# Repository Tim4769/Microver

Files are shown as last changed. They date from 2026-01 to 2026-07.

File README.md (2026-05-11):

# Microver

Microver rover

Microver is a compact rover built for the Swiss Rover Challenge. This repository collects the project's electronics, mechanical CAD, software scaffold, PCB test firmware, photos, and shared assets in one place.

## Project

- **Competition:** Swiss Rover Challenge, Switzerland's rover competition for teams of 5 high school students.
- **2025 result:** 3rd place.
- **2026 result:** 1st place.
- **Main disciplines:** electronics, mechanical design, and software.

## Start Here

| Area | Path | Contents |
|---|---|---|
| Electronics | `hardware/final/README.md` | Active PCB revisions, KiCad projects, manufacturing outputs, and validation notes. |
| Mechanical | `mechanical/README.md` | Rover assemblies, wheel pods, chassis parts, mechanisms, mounts, and STEP exports. |
| Software | `software/` | Python rover-control scaffold with camera and control services. |
| PCB test firmware | `hardware/pcb_testing_firmware/README.md` | Arduino sketches and docs for board bring-up and electronics validation. |
| Power diagrams | `hardware/flow_charts/README.md` | Power-system flow charts and supporting diagrams. |

## Current Snapshot

**Electronics**
- Manufacturing-ready PCB work is under `hardware/final/`; archived board spins live under `hardware/archive/`.
- The active stack covers protection Rev B, boost Rev C, buck Rev C, high-side OR-ing Rev A, compute Rev A, and final control Rev A.

**Mechanical**
- Modular CAD lives in `mechanical/assemblies/` and `mechanical/components/`.
- The rover uses field-serviceable wheel pods, aluminium extrusion rails, custom 3D-printed parts, and integrated mounts for electronics, sensors, and mechanisms.

**Software**
- `software/` is the autonomy-ready rover software workspace for control, camera, perception, navigation, and system integration.
- `hardware/pcb_testing_firmware/` contains electronics bring-up and validation sketches only; it is separate from the final software stack.

## Repository Map

- `hardware/` - PCB designs, manufacturing files, archived board revisions, power diagrams, and PCB validation firmware.
- `mechanical/` - CAD assemblies, exported STEP components, manufacturing notes, and mechanical integration references.
- `software/` - Raspberry Pi control software scaffold and future rover software workspace.
- `photos/` - Build, test, and competition photos.
- `logo/` - Current and legacy logo assets.
- `jingle/` - Project audio assets.
- `Microver_presentation_final.pdf` - Final presentation and system overview.

## Maintenance Notes

- Keep generated PCB outputs inside the relevant board revision folder.
- Update CAD references when board dimensions, connector orientation, sensor placement, or mounting details change.
- Keep editable CAD, exported review files, and assembly notes together.
- Keep PCB validation sketches separate from final rover software.
- Update this README when top-level folders move or new subsystem entry points are added.

## License / Contact

All rights reserved. No permission is granted to use, copy, modify, or distribute this repository or its contents without prior written consent. See `LICENSE` for exact terms.

Contact: Tim Wang - timwang007@outlook.com.

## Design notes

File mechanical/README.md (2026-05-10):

# Hardware — Mechanical

## Overview

Microver is a compact competition rover built for the [Swiss Rover Challenge](../Documentation/Swiss-Rover-Challenge-Rulebook-2026-v1.pdf). The mechanical design prioritises modularity — the wheel pod system supports both 4-wheel and 6-wheel drive configurations by sliding in and out of aluminium extrusion rails, making field reconfiguration straightforward. All structural parts are custom 3D printed, with the complete assembly designed in Autodesk Fusion 360.

---

## Folder Structure

```
hardware/
├── assemblies/                  # Full and sub-assembly STEP files
│   ├── Microver assembly.step   # Top-level full rover assembly
│   └── Wheel pod assembly.step  # Modular wheel pod sub-assembly
└── components/
    ├── Chassis/                 # Base plate and aluminium extrusions
    ├── body/                    # Hood, mechanisms, servo mounts, and body parts
    ├── drivetrain/              # Wheel pod internal components
    └── electronics/             # PCBs, mounts, and power components
```

---

## Assemblies

### Full Rover — `assemblies/Microver assembly.step`

Top-level assembly of the complete rover, combining all sub-assemblies and components.

---

### Wheel Pod Assembly — `assemblies/Wheel pod assembly.step`

A modular drivetrain unit that slides in and out of the aluminium extrusion rails, enabling 4WD or 6WD configurations without structural modification. One assembly is used per wheel.

| File | Type | Description |
|---|---|---|
| `drivetrain/hub.step` | Custom | Wheel hub |
| `drivetrain/Motor Coupler.step` | Custom | Couples DC motor shaft to wheel hub |
| `drivetrain/motor holder.step` | Custom | Holds DC motor within the pod |
| `drivetrain/wheel covers with hole in the middle.step` | Custom | Wheel cap/cover |
| `drivetrain/dc-motor-encoder.step` | Manufacturer | DC motor with integrated encoder |
| `drivetrain/Ball bearing.step` | Off-the-shelf | Standard ball bearing |
| `body/extrusion connector component.step` | Custom | Interfaces wheel pod to aluminium extrusion rail |

---

### Chassis

The structural frame of the rover. The base plate mounts onto aluminium extrusion rails via L-brackets, which also act as the sliding rails for the wheel pod assemblies.

| File | Type | Description |
|---|---|---|
| `Chassis/base plate final.step` | Custom | Main structural plate — 30×15.8 cm (overall width 34×19.5 cm) |
| `Chassis/aluminium extrusion.step` | Off-the-shelf | Aluminium extrusion rails |
| `body/L-bracket.step` | Off-the-shelf | HBLBS5 L-bracket, connects extrusions to base plate |

---

### Hook Mechanism

A large MG996R servo drives a hook arm used to grab small payloads and deliver them to a stash location.

| File | Type | Description |
|---|---|---|
| `body/hook microver.step` | Custom | Hook arm |
| `body/servo motor v4 continuation.step` | Custom | Custom MG996R servo mount/bracket |
| `body/Servo+MG996R.step` | Manufacturer | MG996R servo |

---

### Trap Box Assembly

A servo-operated mechanism that releases small pellets from beneath the rover. The pellets are dropped behind the rover to cause competing rovers to slip.

| File | Type | Description |
|---|---|---|
| `body/Trap box.step` | Custom | Pellet container housing |
| `body/MG90S_motorholder.step` | Custom | MG90S servo mount |
| `body/MG90S servo.step` | Manufacturer | MG90S servo (trap door actuation) |

---

### Flag Mechanism

A small MG90S servo raises a flag on the side of the rover.

| File | Type | Description |
|---|---|---|
| `body/Flag holder.step` | Custom | Flag arm/holder |
| `body/MG90S_motorholder.step` | Custom | MG90S servo mount |
| `body/MG90S servo.step` | Manufacturer | MG90S servo (flag actuation) |

---

### Hood Assembly

A 3-part protective cover for the rover's internal components. Also serves as the mounting platform for the camera, LIDAR, and WiFi antenna.

| File | Type | Description |
|---|---|---|
| `body/Microver hood.step` | Custom | Hood (front, main, and back sections) |
| `body/LIDAR.step` | Manufacturer | Slamtec C1M1 LIDAR — used for autonomous navigation |
| `body/RPi_Camera_V2.1.step` | Manufacturer | Raspberry Pi Camera V2.1 |

---

## Component Catalogue

### Custom Designed Parts

| Component | File | Description |
|---|---|---|
| Base plate | `Chassis/base plate final.step` | Main structural plate, 30×15.8 cm |
| Aluminium extrusion connector | `body/extrusion connector component.step` | Wheel pod–to–extrusion rail interface |
| Wheel hub | `drivetrain/hub.step` | Wheel hub |
| Motor coupler | `drivetrain/Motor Coupler.step` | Shaft-to-hub coupling |
| Motor holder | `drivetrain/motor holder.step` | DC motor mount within wheel pod |
| Wheel cover | `drivetrain/wheel covers with hole in the middle.step` | Wheel cap |
| Hood | `body/Microver hood.step` | 3-part protective body cover |
| Hook arm | `body/hook microver.step` | Payload hook arm |
| MG996R servo mount | `body/servo motor v4 continuation.step` | Large servo bracket |
| MG90S servo holder | `body/MG90S_motorholder.step` | Small servo mount (shared by trap & flag) |
| Trap box | `body/Trap box.step` | Pellet dispenser housing |
| Flag holder | `body/Flag holder.step` | Flag arm |
| Fan mount | `body/Fan microver.step` | Electronics cooling fan mount |
| Fan holder | `body/fan holder.step` | Secondary fan bracket |
| PCB mount | `electronics/PCB mount.step` | PCB mounting bracket |
| Raspberry Pi 5 holder | `electronics/Pi5_holder.step` | Raspberry Pi 5 mount |
| PCB spacer | `electronics/Spacer PCB.step` | PCB standoff spacer |
| Logo model | `body/CK Project model.step` | Project CK logo |

### Manufacturer / Off-the-Shelf Models

| Component | File | Source |
|---|---|---|
| Aluminium extrusion | `Chassis/aluminium extrusion.step` | microver.ch competition |
| L-bracket (HBLBS5) | `body/L-bracket.step` | microver.ch competition |
| MG996R servo | `body/Servo+MG996R.step` | microver.ch competition |
| MG90S servo | `body/MG90S servo.step` | microver.ch competition |
| DC motor w/ encoder | `drivetrain/dc-motor-encoder.step` | microver.ch competition |
| Ball bearing | `drivetrain/Ball bearing.step` | microver.ch competition |
| LIDAR (Slamtec C1M1) | `body/LIDAR.step` | microver.ch competition |
| Raspberry Pi Camera V2.1 | `body/RPi_Camera_V2.1.step` | microver.ch competition |
| Raspberry Pi 5 | `electronics/Raspberry Pi.step` | Electronics supplier |
| Einhell 2.5Ah battery | `electronics/Battery/einhell-2.5Ah.step` | microver.ch competition |
| Power receiver | `electronics/Battery/power-receiver-public-document.step` | microver.ch competition |
| E-stop | `electronics/e-stop.step` | microver.ch competition |
| Boost converter PCB | `electronics/Boost converter_3D.step` | Custom PCB manufacturer |
| Buck converter PCB | `electronics/Buck_3D.step` | Custom PCB manufacturer |
| High Side OR-ing PCB | `electronics/High Side OR ing_3D.step` | Custom PCB manufacturer |
| Modular board PCB | `electronics/Microver2026_Modular_Final_3D.step` | Custom PCB manufacturer |
| STM32 control PCB | `electronics/Microver2026_STM32_Control_3D.step` | Custom PCB manufacturer |

---

## Manufacturing

All custom parts were designed in Autodesk Fusion 360 and 3D printed in-house.

**Printers:** Bambu Lab H2D and X1C

**Materials:**
- **PLA Basic** — all structural parts
- **TPU** — tyres (for maximum grip and elasticity)

**Sourcing:** Off-the-shelf hardware components (brackets, extrusions, motors, sensors) were sourced from the microver.ch competition. Electronics were sourced separately.

---

## Status

All parts are finalised as of the 2026 competition season.

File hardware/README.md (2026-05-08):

# Hardware Index

Use this index to avoid opening stale revisions by accident.

## Start here
- `final/README.md` - Latest board revisions (active work only).

## Historical revisions
- `archive/README.md` - Archived revisions and legacy boards.

## Important after folder moves
- KiCad output paths in project files may still point to old folder locations.
- After moving a board revision, update KiCad plot and export paths (Gerber, drill, BOM, CPL) before regenerating manufacturing outputs.

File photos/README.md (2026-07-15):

# Photos

Project photos for Microver design, build, testing, and competition documentation.

## Folders
- `2024-2025/` - Earlier design, testbench, and development photos.
- `2025-2026/` - Final rover, build, electronics, and competition-season photos.

Keep board-specific engineering photos inside the relevant board folder when they document a PCB revision. Use this folder for project-level photos.

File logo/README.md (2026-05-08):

# Logo Assets

Logo source files, exports, and legacy reference images for Microver branding.

## Folders
- `logos_current/` - Current logo source and export files.
- `logos_legacy/` - Older logo files kept for reference only.

Use the current folder for new presentations, documentation, and public-facing materials unless a legacy file is explicitly needed for comparison.

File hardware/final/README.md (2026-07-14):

# Current Hardware (Start Here)

These are the active board folders. Use these for new builds and current engineering updates.
Each board folder keeps its working KiCad project in a local `Kicad_*` subdirectory next to generated manufacturing files when those outputs are available.

## Complete Board Assembly

Complete Microver hardware stack with every board assembled together

*This photo shows every board assembled together as the complete hardware stack, not only the final control board.*

- `protection_board_manufacturing_rev_b/`
- `boost_manufacturing_rev_c/`
- `buck_manufacturing_rev_c/`
- `High_Side_OR_ing_manufacturing_rev_a/`
- `final_compute_STM32_rev_a/`
- `final_compute_arduinos_rev_a/`
- `final_control_board_rev_a/`

Field testing and competition notes for the motor-driver voltage mismatch, boost/buck removal, motor change, Raspberry Pi power-drop hypotheses, and second motor-driver `OUTA` / `OUTB` rework are recorded in `final_control_board_rev_a/README.md`.

Archived or superseded board folders live under `../archive/`.

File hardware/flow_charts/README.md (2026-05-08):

# Flow Charts

Exported power-system flow-chart images for Microver hardware handoff and review.

## Files
- `Power system.png` - Full power-system overview.
- `Power system - Protection.png` - Protection-board path.
- `Power system - Buck.png` - Buck-converter path.
- `Power system - Boost.png` - Boost-converter path.
- `Power system - ORing.png` - High-side OR-ing path.

Keep exported diagrams here as PNGs. If an editable source file is added later, keep it in this folder and refresh the PNG exports with the same names when possible.

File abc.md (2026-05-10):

<<<<<<< HEAD
# Microver

Microver rover

Microver is a small rover project organized around three equally important parts: electronics, mechanical design, and software. The project was built for the Swiss Rover Challenge, Switzerland's high-school robotics championship where teams design, build, and operate Mars rover prototypes.

This repository keeps the project work together: final board files, mechanical handoff material, future rover software space, PCB testing firmware, documentation, and shared project assets.

## Project 
**Swiss Rover Challenge**
- Format: teams of 3-4 high-school students build and operate Mars rover prototypes.
- 2025 edition: Institut Le Rosey, Rolle, Switzerland, Saturday, May 31, 2025.
- 2026 edition: College Alpin Beau Soleil, Villars-sur-Ollon, Switzerland, Sunday, May 3, 2026.

**Team roles**
- Tim / Tianran Wang - team lead and electrical engineer.
- Lucas / Haolin Liu - software engineer.
- Taiyo - software engineer.
- Pat / Chawanvit Tangwongsiri - mechanical engineer.
- Steven Bang - mechanical engineer.

**Team results**
- 2025 Swiss Rover Challenge: 3rd place.
- 2026 Swiss Rover Challenge: 1st place.

## Project Parts
**Electronics**
- Purpose: power entry, conversion, motor drive, compute interconnects, and final rover control boards.
- Start here: `hardware/final/README.md`.
- Supporting material: `flow_charts/README.md` for power-system diagrams.
- Completed status: active board work lives under `hardware/final/`; older spins remain under `hardware/archive/`.

**Mechanical**
- Purpose: CAD, mounting, chassis, packaging, and physical integration for the rover.
- Start here: `mechanical/README.md`.
- Supporting material: board photos and physical reference files inside the hardware folders.
- Completed status: mechanical handoff area is tracked and ready for final CAD, drawings, assembly notes, and mount details.

**Software**
- Purpose: Raspberry Pi control software, Arduino motor/encoder firmware, diagnostics, pin maps, messaging, and handoff documentation.
- Start here: `firmware/README.md`.
- Supporting material: `pcb_testing_firmware/README.md` for electronics bring-up and PCB validation sketches.
- Current status: `firmware/` is reserved for the rover software lead to update later; existing Arduino test code lives in `pcb_testing_firmware/` and is not the competition software.

## Current Snapshot
**Electronics**
- Protection board: Rev B.
- Boost converter: Rev C.
- Buck converter: Rev C.
- High-side OR-ing board: Rev A.
- Final compute boards: STM32 Rev A and dual-Arduino Rev A.
- Final control board: Rev A.

**Mechanical**
- Mechanical folder is tracked and documented.
- `mechanical/placeholder.rtf` is present until final CAD or drawing files are added.
- Future mechanical files should keep source CAD, exported drawings, assembly notes, and mounting references together.
- Mechanical integration should stay aligned with board footprints, connector access, and software sensor/actuator assumptions.

**Software**
- `firmware/` is a placeholder for the future rover software maintained by the software lead.
- `pcb_testing_firmware/` contains PCB testing, electronics bring-up sketches, diagnostics, and references.
- `pcb_testing_firmware/archive/2024_code/` contains older experiments for historical reference.
- Existing test sketches should be treated as board validation tools, not as the final competition software stack.
- The final presentation describes the competition software architecture as a Raspberry Pi Python host communicating with two Arduino Nano Every boards over serial: one for motors/servos and one for encoder data.
- The planned control stack included joystick remote control, live camera feed, low-level PID, Pure Pursuit, and AMCL localization using LIDAR.

## Repository Map
**Electronics**
- `hardware/` - Board projects and release organization.
- `hardware/final/` - Latest board revisions for the completed 2026 rover.
- `hardware/archive/` - Historical board revisions and rollback references.
- `flow_charts/` - Exported power-system flow-chart PNGs.

**Mechanical**
- `mechanical/` - Mechanical handoff area for CAD, drawings, mounts, and assembly notes.

**Software**
- `firmware/` - Future rover software folder for the software lead.
- `pcb_testing_firmware/` - PCB testing and electronics bring-up firmware.
- `pcb_testing_firmware/2026/` - Final-stack board validation sketches and handoff notes.
- `pcb_testing_firmware/2025/` - Earlier Arduino testing sketches, diagnostics, docs, and references.
- `pcb_testing_firmware/archive/` - Legacy experiments and older code snapshots.

**Shared Assets**
- `Microver_presentation_final.pdf` - Final presentation with team roles, project timeline, and system overview.
- `logo/` - Current and legacy logo assets.
- `jingle/` - Microver jingle audio files.
- `photos/` - Project photos from design, build, testing, and competition seasons.
- `LICENSE` - All rights reserved terms.

## Quick Start
**Electronics**
- Start in `hardware/final/` and choose the latest revision folder for the board you are building, reviewing, or documenting.
- Use each board's local `Kicad_*` folder for schematic/layout changes.
- Use `Gerber/`, `Gerber.zip`, `BOM.csv`, and `CPL.csv` when generated manufacturing outputs are available.
- For protection-board validation, use `hardware/final/protection_board_manufacturing_rev_b/test_procedure_rev_b.md`.

**Mechanical**
- Start in `mechanical/` and replace the placeholder with source CAD, exported drawings, or assembly notes when available.
- Keep mechanical files organized by rover subsystem or assembly if the folder grows.
- Check board dimensions, mounting holes, connector access, and cable paths against the active electronics folders.
- Add assembly notes next to the related CAD/drawing files so the physical build is traceable.

**Software**
- Start in `firmware/` when adding the future rover software.
- Use `pcb_testing_firmware/2026/docs/board-validation-software-handoff.md` only for board validation pin maps and test flow.
- Use `pcb_testing_firmware/2026/docs/power-and-actuator-control-handoff.md` for power-control and actuator bring-up notes.
- Run focused test sketches from `pcb_testing_firmware/2026/controllers/` when validating PCBs or electronics.

## Detailed Navigation
**Electronics**
- `hardware/final/protection_board_manufacturing_rev_b/` - Latest protection board.
- `hardware/final/boost_manufacturing_rev_c/` - Latest boost converter.
- `hardware/final/buck_manufacturing_rev_c/` - Latest buck converter.
- `hardware/final/High_Side_OR_ing_manufacturing_rev_a/` - Latest high-side OR-ing board.
- `hardware/final/final_compute_STM32_rev_a/` - STM32 compute board.
- `hardware/final/final_compute_arduinos_rev_a/` - Dual-Arduino compute board.
- `hardware/final/final_control_board_rev_a/` - Main control and distribution board.

**Mechanical**
- `mechanical/README.md` - Mechanical folder guide.
- `mechanical/placeholder.rtf` - Temporary tracked placeholder.
- Board photos in `hardware/final/*/Photo.JPG` are useful physical references for mechanical integration.

**Software**
- `firmware/README.md` - Future rover software folder guide.
- `pcb_testing_firmware/2026/controllers/` - Final-stack PCB testing sketches.
- `pcb_testing_firmware/2026/docs/board-validation-software-handoff.md` - Board validation pin maps, serial commands, and test flow.
- `pcb_testing_firmware/2026/docs/power-and-actuator-control-handoff.md` - Power and actuator bring-up notes.
- `pcb_testing_firmware/2025/diagnostics/` - Earlier focused subsystem checks.

## Maintenance Notes
**Electronics**
- After KiCad edits, regenerate Gerbers, drill files, BOM, CPL, and assembly drawings as needed.
- Keep generated outputs inside the relevant board folder.
- Add test logs as `test_procedure_<rev>.md` or `validation_notes.md`.

**Mechanical**
- Keep editable source files and exported review files together.
- Record fit, clearance, mounting, and assembly changes in README or notes files near the CAD.
- When electronics move or connector orientation changes, update mechanical references at the same time.

**Software**
- Keep future rover software under `firmware/`.
- Keep PCB validation sketches under `pcb_testing_firmware/`.
- Keep pin-map changes synchronized with the hardware and mechanical layout.
- Document PCB test protocol, baud-rate, actuator, and watchdog changes in `pcb_testing_firmware/2026/docs/`.

## License / Contact
All rights reserved. No permission is granted to use, copy, modify, or distribute this repository or its contents without prior written consent. See `LICENSE` for exact terms. Contact: Tim Wang - timwang007@outlook.com.
=======
# microver

```bash
make
```
>>>>>>> 239cfc1 (Pushing code)

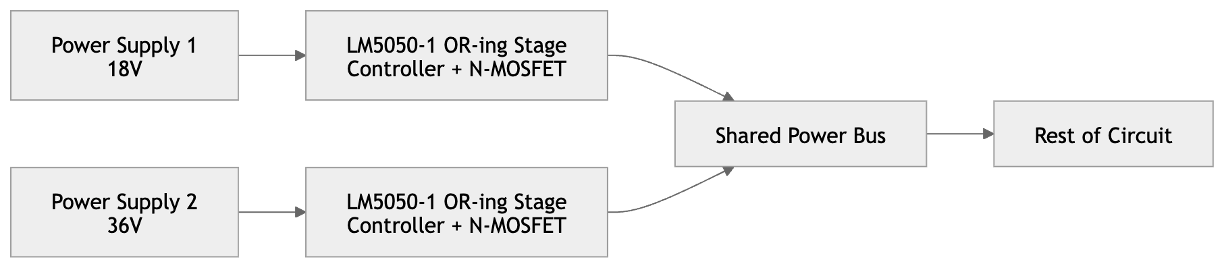
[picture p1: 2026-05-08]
hardware/flow_charts/Power system - ORing.png

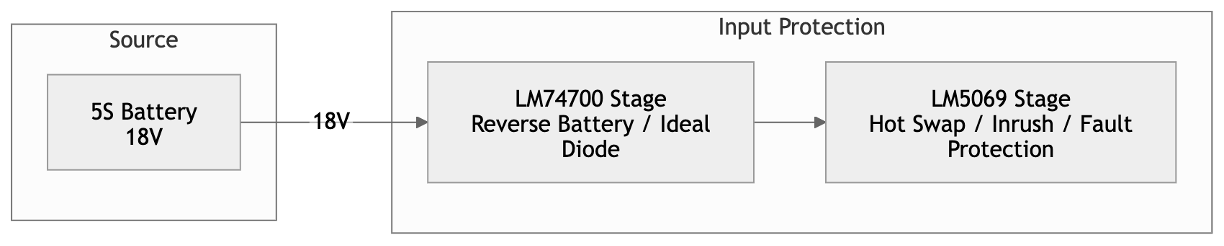
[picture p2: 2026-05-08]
hardware/flow_charts/Power system - Protection.png

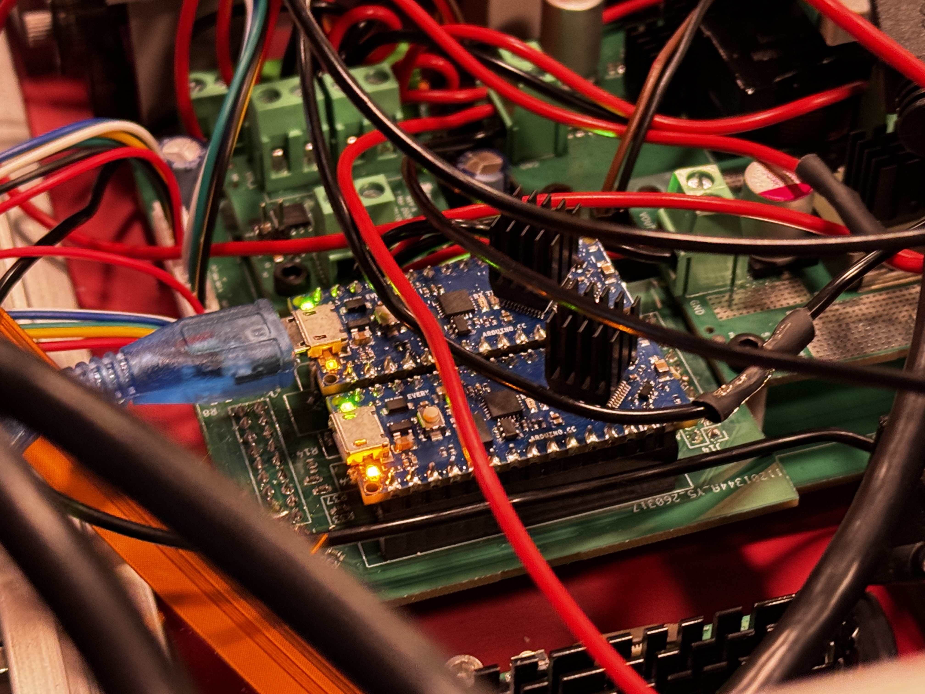
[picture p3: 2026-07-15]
hardware/final/final_compute_arduinos_rev_a/Photo.JPG

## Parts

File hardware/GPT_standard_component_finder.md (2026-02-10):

# Standard Component Finder GPT

## What it does
- Finds the closest standard resistor or capacitor values to a user-specified target, covering the entire range (including ultra-low and ultra-high values).
- Uses only commonly stocked E-series values (E12 or E24) and basic-library parts.
- Always returns three buckets per query: best match, nearest lower, nearest higher.
- Proposes up to three-part combinations (series/parallel) when they yield a closer effective value.
- Reports percentage error for every result, including perfect matches (0%).
- Responds concisely and technically—no extra context (voltage, tolerance, dielectric, etc.).

## Output style
- Clean table or bullet list with columns/fields for: configuration (single / series / parallel), component values used, computed equivalent, and % error.
- Applies the same format to single values and multi-component combos.
- No prompting required for range extremes; it auto-considers all valid E12/E24 values.

## Creation notes (prompt highlights)
- Primary goal: “Identify standard resistor/capacitor options that best match a target value using E12/E24 values; include nearest lower/higher and small combinations up to three parts; show % error for every entry.”
- Constraints: basic-library parts only; keep answers short and technical; exclude contextual advice.
- Combination logic: compute series/parallel equivalents, pick the closest match, and still surface the next lower/higher single-value options.
- Formatting rule: always include a % error column/field, even when the error is 0%.

## Usage
1) Provide a target value (e.g., “82 kΩ” or “3.3 µF”). No extra parameters needed.
2) The GPT responds with best/nearest-lower/nearest-higher single values plus any tighter series/parallel combos (up to 3 parts), each with % error.
3) Copy the suggested standard values directly into schematics/BOMs as needed.

## Link
- ChatGPT GPT: https://chatgpt.com/g/g-696bbc706f4c8191a6ac34a9fc48d9c7-standard-value-finder

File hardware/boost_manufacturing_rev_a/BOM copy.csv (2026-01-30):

Reference | Qty | Value | Footprint | Datasheet | JPCPCB part number
C1,C4,C7 | 3 | 220uF | Capacitor_THT:CP_Radial_D10.0mm_P5.00mm | ~ | C106670
C2,C5,C8,C10 | 4 | 100nF | Capacitor_SMD:C_0603_1608Metric | ~ | C14663
C3 | 1 | 1uF | Capacitor_SMD:C_0805_2012Metric | ~ | C28323
C6 | 1 | 6.8uF | Capacitor_SMD:C_0603_1608Metric | ~ | C338096
C9 | 1 | 47nF | Capacitor_SMD:C_0603_1608Metric | ~ | C1622
D1,D2 | 2 | D_TVS | Diode_SMD:D_SMB | ~ | C19077586
D3 | 1 | D_Schottky | Diode_SMD:D_SMC | ~ | C134457
D4 | 1 | 1N4148W | Diode_SMD:D_SOD-123 | https://www.vishay.com/docs/85748/1n4148w.pdf | C7420318
J1,J3 | 2 | Conn_01x02_Socket | TerminalBlock:TerminalBlock_MaiXu_MX126-5.0-02P_1x02_P5.00mm | ~
J2 | 1 | Conn_01x02_Socket | Connector_PinHeader_2.54mm:PinHeader_1x02_P2.54mm_Vertical | ~
Q1,Q2,Q3 | 3 | CSD19536KTT | KTT0002A | https://www.ti.com/lit/gpn/csd19536ktt | C2687963
R1,R5 | 2 | 47kΩ | Resistor_SMD:R_0603_1608Metric | ~ | C25819
R2,R6 | 2 | 620Ω | Resistor_SMD:R_0603_1608Metric | ~ | C23220
R3 | 1 | 180Ω | Resistor_SMD:R_0603_1608Metric | ~ | C22828
R4 | 1 | 7.5kΩ | Resistor_SMD:R_0603_1608Metric | ~ | C23234
R7 | 1 | 4.3kΩ | Resistor_SMD:R_0603_1608Metric | ~ | C23159
R8 | 1 | 33Ω | Resistor_SMD:R_0603_1608Metric | ~ | C23140
R9,R10 | 2 | 5mΩ | Resistor_SMD:R_2512_6332Metric | ~ | C108931
R11,R12 | 2 | 10Ω | Resistor_SMD:R_0603_1608Metric | ~ | C22859
R13 | 1 | 22kΩ | Resistor_SMD:R_0603_1608Metric | ~ | C31850
R14 | 1 | 100kΩ | Resistor_SMD:R_0603_1608Metric | ~ | C25803
R15 | 1 | 1kΩ | Resistor_SMD:R_0603_1608Metric | ~ | C21190
U1 | 1 | LM74700QDBVRQ1 | DBV0006A_N | https://www.ti.com/lit/gpn/lm74700-q1 | C2941042
U2 | 1 | LM5069MMX-2/NOPB | MUB10A | https://www.ti.com/lit/gpn/lm5069 | C2653582
U3 | 1 | MMBT5401LT1G | SOT-23-3_1P4X3P040_ONS | MMBT5401LT1G | C21488

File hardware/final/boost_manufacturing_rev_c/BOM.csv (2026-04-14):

Reference | Qty | Value | Footprint | Datasheet | JLCPCB Part number
C1 | 1 | 150pF | Capacitor_SMD:C_0603_1608Metric | ~ | C1594
C2 | 1 | 470nF | Capacitor_SMD:C_0805_2012Metric | ~ | C13967
C3 | 1 | 220nF | Capacitor_SMD:C_0603_1608Metric | ~ | C21120
C4 | 1 | 1uF | Capacitor_SMD:C_0805_2012Metric | ~ | C28323
C5 | 1 | 470nF | Capacitor_SMD:C_0603_1608Metric | ~ | C1623
C6 | 1 | 680pF | Capacitor_SMD:C_0603_1608Metric | ~ | C1630
C7 | 1 | 220nF | Capacitor_SMD:C_0805_2012Metric | ~ | C5378
C8,C9,C11,C13,C14,C15,C16,C17,C18,C19,C20 | 11 | 10uF | Capacitor_SMD:C_0805_2012Metric | ~ | C440198
C10,C12 | 2 | 470uF | Capacitor_THT:CP_Radial_D10.0mm_P5.00mm | ~ | C5438877
D1 | 1 | D_Schottky | Diode_SMD:D_SMA | ~ | C18199198
J1,J2 | 2 | Conn_01x02_Socket | TerminalBlock_MetzConnect:TerminalBlock_MetzConnect_Type055_RT01502HDWU_1x02_P5.00mm_Horizontal | ~
J4 | 1 | Conn_01x02_Pin | Connector_PinHeader_2.54mm:PinHeader_1x02_P2.54mm_Vertical | ~
L1 | 1 | 10uH | Boost_Converter_Footprint_Library:IND_SER2918H_COC | ~ | C3037600
MOSFET1 | 1 | 2N7002 | Boost_Converter_Footprint_Library:SOT-23TO-236_318-08_ONS | 2N7002 | C8545
Q1,Q2,Q3,Q4 | 4 | CSD18540Q5B | Boost_Converter_Footprint_Library:DNK0008A | https://www.ti.com/lit/gpn/csd18540q5b | C86513
R1 | 1 | 49.9kΩ | Resistor_SMD:R_0603_1608Metric | ~ | C23184
R2 | 1 | 5.1kΩ | Resistor_SMD:R_0603_1608Metric | ~ | C23186
R3,R13 | 2 | 100Ω | Resistor_SMD:R_0603_1608Metric | ~ | C22775
R4 | 1 | 3.01Ω | Resistor_SMD:R_0603_1608Metric | ~ | C49655781
R5 | 1 | 2mΩ | Resistor_SMD:R_2512_6332Metric | ~ | C728306
R6,R8 | 2 | 160kΩ | Resistor_SMD:R_0603_1608Metric | ~ | C22813
R7,R12 | 2 | 56kΩ | Resistor_SMD:R_0603_1608Metric | ~ | C23206
R9,R16,R17,R18 | 4 | 2Ω | Resistor_SMD:R_0603_1608Metric | ~ | C22977
R10 | 1 | 2kΩ | Resistor_SMD:R_0603_1608Metric | ~ | C22975
R11 | 1 | 12kΩ | Resistor_SMD:R_0603_1608Metric | ~ | C22790
R14 | 1 | 1.5kΩ | Resistor_SMD:R_0603_1608Metric | ~ | C22843
R15 | 1 | 270kΩ | Resistor_SMD:R_0603_1608Metric | ~ | C22965
U1 | 1 | LM5122QMHX/NOPB | Boost_Converter_Footprint_Library:HTSSOP20 | https://www.ti.com/lit/gpn/lm5122-q1 | C527477

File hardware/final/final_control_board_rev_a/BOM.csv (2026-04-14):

Reference | Qty | Value | Exclude from BOM | Footprint | JLCPCB Part Number
C1,C3,C7,C16 | 4 | 220uF |  | Capacitor_THT:CP_Radial_D8.0mm_P3.50mm | C106697
C2,C6 | 2 | 4.7uF |  | Capacitor_SMD:C_0603_1608Metric | C19666
C4,C5 | 2 | 4.7 uF |  | Capacitor_SMD:C_1206_3216Metric | C29823
C8,C9 | 2 | 220 uF |  | Capacitor_SMD:CP_Elec_4x5.4 | C116389
D1 | 1 | 3.3V |  | LED_SMD:LED_0603_1608Metric | C126319
D2 | 1 | 5V |  | LED_SMD:LED_0603_1608Metric | C22371297
D3 | 1 | 18V |  | LED_SMD:LED_0603_1608Metric | C22371297
F1 | 1 | Fuse |  | microver footprint Library:Fuse PTF-77 | C717030
H2 | 1 | Boost/Prot | Excluded from BOM | MountingHole:MountingHole_3.2mm_M3
H3 | 1 | Prot | Excluded from BOM | MountingHole:MountingHole_3.2mm_M3
H4,H5,H6,H8,H9,H10,H11,H12,H13,H14 | 10 | MountingHole | Excluded from BOM | MountingHole:MountingHole_3.2mm_M3
J1 | 1 | Fan control |  | Connector_PinHeader_2.54mm:PinHeader_1x03_P2.54mm_Vertical | C2937625
J2 | 1 | PGD_Prot |  | Connector_PinHeader_2.54mm:PinHeader_1x02_P2.54mm_Vertical | C492401
J3 | 1 | on/off_Boost |  | Connector_PinHeader_2.54mm:PinHeader_1x02_P2.54mm_Vertical | C492401
J10 | 1 | Drive_1 |  | Connector_JST:JST_PH_B6B-PH-K_1x06_P2.00mm_Vertical
J11 | 1 | Drive_2 |  | Connector_JST:JST_PH_B6B-PH-K_1x06_P2.00mm_Vertical
J12 | 1 | Drive_3 |  | Connector_JST:JST_PH_B6B-PH-K_1x06_P2.00mm_Vertical
J13 | 1 | Drive_4 |  | Connector_JST:JST_PH_B6B-PH-K_1x06_P2.00mm_Vertical
J14 | 1 | Left |  | Connector_PinHeader_2.54mm:PinHeader_2x10_P2.54mm_Vertical | C492427
J15 | 1 | Right |  | Connector_PinHeader_2.54mm:PinHeader_2x10_P2.54mm_Vertical | C492427
J16 | 1 | Drive_5 |  | Connector_JST:JST_PH_B6B-PH-K_1x06_P2.00mm_Vertical
J17 | 1 | Drive_6 |  | Connector_JST:JST_PH_B6B-PH-K_1x06_P2.00mm_Vertical
J18 | 1 | Lidar pins |  | Connector_JST:JST_XH_B5B-XH-AM_1x05_P2.50mm_Vertical
J19 | 1 | VIN_5V |  | Connector_Wire:SolderWire-0.75sqmm_1x02_P7mm_D1.25mm_OD3.5mm | C8269
J20 | 1 | Spare pins |  | Connector_PinHeader_2.54mm:PinHeader_1x05_P2.54mm_Vertical | C492404
J24 | 1 | Servo 1 |  | Connector_PinHeader_2.54mm:PinHeader_1x03_P2.54mm_Vertical | C2937625
J25 | 1 | Servo 2 |  | Connector_PinHeader_2.54mm:PinHeader_1x03_P2.54mm_Vertical | C2937625
J26 | 1 | Servo 3 |  | Connector_PinHeader_2.54mm:PinHeader_1x03_P2.54mm_Vertical | C2937625
J27 | 1 | Servo 4 |  | Connector_PinHeader_2.54mm:PinHeader_1x03_P2.54mm_Vertical | C2937625
J28 | 1 | VOUT_Higher |  | Connector_Wire:SolderWire-0.75sqmm_1x02_P7mm_D1.25mm_OD3.5mm | C8269
J29 | 1 | Pi 5 TX and RX UART0 (PL011) |  | Connector_PinHeader_2.54mm:PinHeader_1x02_P2.54mm_Vertical | C492401
J30 | 1 | Pi power pins |  | Connector_PinHeader_2.54mm:PinHeader_1x02_P2.54mm_Vertical | C492401
J31 | 1 | VIN_Pre |  | TerminalBlock:TerminalBlock_MaiXu_MX126-5.0-02P_1x02_P5.00mm | C8269
J32 | 1 | VOUT_Pre |  | Connector_Wire:SolderWire-0.75sqmm_1x02_P7mm_D1.25mm_OD3.5mm | C8269
R1 | 1 | 330Ω |  | Resistor_SMD:R_0603_1608Metric | C23138
R2 | 1 | 1.2kΩ |  | Resistor_SMD:R_0603_1608Metric | C22765
R3 | 1 | 6.8kΩ |  | Resistor_SMD:R_0603_1608Metric | C23212
SW1 | 1 | 1MS1T1B1M2QES |  | Microver2026_Modular_Footprint:SS-12D10G5_XKB | C319012
SW2 | 1 | SW_SPDT |  | Connector_Wire:SolderWire-0.5sqmm_1x03_P4.8mm_D0.9mm_OD2.3mm
TH1 | 1 | Thermistor_NTC | Excluded from BOM | microver footprint Library:NTC thermistor Microver
TP1 | 1 | +5V | Excluded from BOM | TestPoint:TestPoint_Pad_1.0x1.0mm
TP2 | 1 | +3.3V | Excluded from BOM | TestPoint:TestPoint_Pad_1.0x1.0mm
TP3,TP4 | 2 | Compute/ENCO_PWR | Excluded from BOM | TestPoint:TestPoint_Pad_1.0x1.0mm
U1,U2 | 2 | VNH5019A-E |  | Buck_Footprint_Library:SOIC_5019A-E_STM | C2653552
U3,U4 | 2 | CSD18543Q3A |  | Buck_Footprint_Library:DNH0008A | C840100
U5 | 1 | MIC5365-3.3YD5 |  | Package_TO_SOT_SMD:SOT-23-5 | C626098

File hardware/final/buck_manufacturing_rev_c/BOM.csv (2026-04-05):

Reference | Qty | Value | Footprint | Datasheet | JLCPCB Part Number
C1 | 1 | 220 uF | Capacitor_SMD:CP_Elec_4x5.4 | ~ | C116389
C2,C3,C4,C6,C7,C9 | 6 | 4.7 uF | Capacitor_SMD:C_1206_3216Metric | ~ | C29823
C5 | 1 | 2.2 μF | Capacitor_SMD:C_0805_2012Metric | ~ | C377773
C8 | 1 | 1uF | Capacitor_SMD:C_0603_1608Metric | ~ | C15849
C10,C12 | 2 | 0.1 μF | Capacitor_SMD:C_0603_1608Metric | ~ | C14663
C11 | 1 | 10 pF | Capacitor_SMD:C_0603_1608Metric | ~ | C1634
C13 | 1 | 4.7nF | Capacitor_SMD:C_0603_1608Metric | ~ | C53987
C14 | 1 | 68pF | Capacitor_SMD:C_0603_1608Metric | ~ | C28262
C15,C16,C18,C19,C20,C22,C23 | 7 | 47 μF | Capacitor_SMD:C_1210_3225Metric | ~ | C96123
C17 | 1 | 2.7nF | Capacitor_SMD:C_0603_1608Metric | ~ | C1609
C21 | 1 | 680 µF | Buck_Footprint_Library:MA35V680M10X13 | ~ | C48971043
C24 | 1 | 1nF | Capacitor_SMD:C_0603_1608Metric | ~ | C1588
D1 | 1 | R LED | LED_SMD:LED_0603_1608Metric | ~ | C2286
J1,J2 | 2 | Conn_01x02_Socket | TerminalBlock:TerminalBlock_MaiXu_MX126-5.0-02P_1x02_P5.00mm | ~ | C8269
L1 | 1 | 3.3uH | Buck_Footprint_Library:MS1770-3R3M | ~ | C18337521
Q1,Q2,Q3,Q4 | 4 | BSC032N04LS | Buck_Footprint_Library:INF-PG-TDSON-8-FL |  | C194147
R1 | 1 | 4.7 kΩ | Resistor_SMD:R_0402_1005Metric | ~ | C25900
R2 | 1 | 33kΩ | Resistor_SMD:R_0603_1608Metric | ~ | C4216
R3 | 1 | 49.9kΩ | Resistor_SMD:R_0603_1608Metric | ~ | C23184
R4 | 1 | 4.7kΩ | Resistor_SMD:R_0603_1608Metric | ~ | C23162
R5 | 1 | 4.3kΩ | Resistor_SMD:R_0603_1608Metric | ~ | C23159
R6 | 1 | 510Ω | Resistor_SMD:R_0603_1608Metric | ~ | C23193
R7 | 1 | 7.5 kΩ | Resistor_SMD:R_0603_1608Metric | ~ | C23234
R8 | 1 | 430Ω | Resistor_SMD:R_0603_1608Metric | ~ | C23170
R9 | 1 | 22kΩ | Resistor_SMD:R_0603_1608Metric | ~ | C31850
R10,R12,R13,R14,R15 | 5 | 2Ω | Resistor_SMD:R_0603_1608Metric | ~ | C22977
R11 | 1 | 1Ω | Resistor_SMD:R_0603_1608Metric | ~ | C22936
R20 | 1 | 9.1kΩ | Capacitor_SMD:C_0603_1608Metric | ~ | C23260
U1 | 1 | LM5146QRGYTQ1 | Buck_Footprint_Library:RGY0020B | https://www.ti.com/lit/gpn/lm5146-q1 | C2876733

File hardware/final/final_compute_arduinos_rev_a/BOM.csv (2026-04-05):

Reference | Qty | Value | Footprint | Datasheet | JLCPCB part number
A1 | 1 | Main_Arduino_Nano_Every | Module:Arduino_Nano | https://content.arduino.cc/assets/NANOEveryV3.0_sch.pdf
A2 | 1 | Sub_Arduino_Nano_Every | Module:Arduino_Nano | https://content.arduino.cc/assets/NANOEveryV3.0_sch.pdf
J14 | 1 | Left | Connector_PinHeader_2.54mm:PinHeader_2x10_P2.54mm_Vertical | ~
J15 | 1 | Right | Connector_PinHeader_2.54mm:PinHeader_2x10_P2.54mm_Vertical | ~
R1 | 1 | 10kΩ | Resistor_SMD:R_0603_1608Metric | ~ | C25804
R2,R3,R4,R5,R6,R8,R10,R16,R18 | 9 | 1kΩ | Resistor_SMD:R_0603_1608Metric | ~ | C21190
R7,R14,R23,R24 | 4 | 3.3kΩ | Resistor_SMD:R_0603_1608Metric | ~ | C22978
R11,R12,R19,R20,R25,R26,R27,R29,R30,R31,R32,R33,R34,R35,R36,R37,R38 | 17 | 100Ω | Resistor_SMD:R_0603_1608Metric | ~ | C22775
R21,R22 | 2 | 4.7kΩ | Resistor_SMD:R_0603_1608Metric | ~ | C23162

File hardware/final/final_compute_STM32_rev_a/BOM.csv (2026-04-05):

Reference | Qty | Value | Footprint | JLCPCB part number
C1,C3,C4,C5,C7,C9,C11 | 7 | 100nF | Capacitor_SMD:C_0603_1608Metric | C14663
C2,C6,C8 | 3 | 4.7uF | Capacitor_SMD:C_0603_1608Metric | C19666
C10,C12 | 2 | 1uF | Capacitor_SMD:C_0603_1608Metric | C15849
C13,C14 | 2 | 10nF | Capacitor_SMD:C_0603_1608Metric | C57112
FB1 | 1 | FerriteBead_Small | Resistor_SMD:R_0603_1608Metric | C14709
J1 | 1 | Pi URAT | Connector_PinHeader_2.54mm:PinHeader_1x02_P2.54mm_Vertical | C492401
J2 | 1 | TC2030 | Connector:Tag-Connect_TC2030-IDC-FP_2x03_P1.27mm_Vertical
J14 | 1 | Left | Connector_PinHeader_2.54mm:PinHeader_2x10_P2.54mm_Vertical
J15 | 1 | Right | Connector_PinHeader_2.54mm:PinHeader_2x10_P2.54mm_Vertical
R1,R2,R3,R4,R5,R7,R8,R11,R18,R19,R20,R21,R23,R25,R28,R30,R32,R33 | 18 | 100Ω | Resistor_SMD:R_0603_1608Metric | C22775
R6,R14,R16,R17,R22,R29,R31 | 7 | 1kΩ | Resistor_SMD:R_0603_1608Metric | C21190
R9,R10,R15,R24,R26 | 5 | 3.3kΩ | Resistor_SMD:R_0603_1608Metric | C22978
R12,R27 | 2 | 680Ω | Resistor_SMD:R_0603_1608Metric | C23228
R13 | 1 | 10kΩ | Resistor_SMD:R_0603_1608Metric | C25804
TP1 | 1 | +5V | TestPoint:TestPoint_Pad_1.0x1.0mm
TP2 | 1 | +3.3V | TestPoint:TestPoint_Pad_1.0x1.0mm
TP3 | 1 | BLDC_PWM | TestPoint:TestPoint_Pad_1.0x1.0mm
TP4 | 1 | DRV1_A | TestPoint:TestPoint_Pad_1.0x1.0mm
TP5 | 1 | DRV1_B | TestPoint:TestPoint_Pad_1.0x1.0mm
TP6 | 1 | DRV2_A | TestPoint:TestPoint_Pad_1.0x1.0mm
TP7 | 1 | DRV1_PWM | TestPoint:TestPoint_Pad_1.0x1.0mm
TP8 | 1 | DRV2_B | TestPoint:TestPoint_Pad_1.0x1.0mm
TP12 | 1 | DRV2_PWM | TestPoint:TestPoint_Pad_1.0x1.0mm
TP15 | 1 | BOOST_EN | TestPoint:TestPoint_Pad_1.0x1.0mm
U1 | 1 | STM32G473RCT6 | STM32_Footprint_Library:LQFP64-10x10mm | C529361
U2 | 1 | MIC5365-3.3YD5 | Package_TO_SOT_SMD:SOT-23-5 | C626098

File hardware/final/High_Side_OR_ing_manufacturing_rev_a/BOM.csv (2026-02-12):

Reference | Qty | Value | Footprint | Datasheet | JLCPCB manufactur number
C1,C2 | 2 | 100nF | Capacitor_SMD:C_0805_2012Metric | ~ | C28233
J1,J2,J3 | 3 | Conn_01x02_Pin | TerminalBlock_MetzConnect:TerminalBlock_MetzConnect_Type011_RT05502HBLC_1x02_P5.00mm_Horizontal | ~
J4,J5 | 2 | Conn_01x01_Pin | Connector_PinHeader_1.00mm:PinHeader_1x01_P1.00mm_Vertical | ~
Q1,Q2 | 2 | TPH2R608NH_L1Q kicad | Or ing_footprint:SOP Advance_TOS | https://ngspice.sourceforge.io/docs/ngspice-html-manual/manual.xhtml#cha_MOSFETs | C5379811
R1,R2 | 2 | 100Ω | Capacitor_SMD:C_0603_1608Metric | ~ | C22775
U1,U2 | 2 | LM5050MKX-1/NOPB | MK06A | https://www.ti.com/lit/gpn/lm5050-1 | C473393

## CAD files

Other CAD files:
mechanical/assemblies/Microver assembly.step
mechanical/assemblies/Wheel pod assembly.step
hardware/final/(not produced) final_control_board_rev_b/Kicad_Microver2026_Modular_Final/3d models/DNH0008A.stp
hardware/final/boost_manufacturing_rev_c/Boost converter_3D.step
hardware/final/buck_manufacturing_rev_c/Buck_3D.step
hardware/final/final_compute_STM32_rev_a/Microver2026_STM32_Control_3D.step
hardware/final/final_control_board_rev_a/Microver2026_Modular_Final_3D.step
hardware/final/High_Side_OR_ing_manufacturing_rev_a/High Side OR ing_3D.step
mechanical/components/body/MG90S servo.step
mechanical/components/Chassis/aluminium extrusion.step
mechanical/components/drivetrain/Motor Coupler.step
mechanical/components/electronics/Battery/power-receiver-public-document.step
mechanical/components/electronics/e-stop.step
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

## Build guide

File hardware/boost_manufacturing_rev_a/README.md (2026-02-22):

# Boost Converter (LM5122-Q1) — Rev A

> DEPRECATED REVISION: For new work, start at `../current/boost_converter/README.md`.

**Owner / Contact:** Tim Wang — timwang007@outlook.com  
**Revision:** Rev A  
**Date:** 2026-01-20

## 1) Overview
High-power synchronous boost converter based on LM5122-Q1, boosting a 24 V class supply to a regulated 36 V DC bus for motor/power electronics. Forced CCM for stable motor loads.

## 2) Electrical specifications
**Input**  
- VIN range: 18–24 V DC  
- Input connector: board edge power input  
- Input current: high (designed for tens of amps on PCB copper)

**Output**  
- VOUT: 36 V nominal  
- Load type: motor bus / dynamic loads  
- Operation mode: forced CCM (MODE = GND)

## 3) PCB stackup (all boards)
- F.Silkscreen (top)
- F.Paste
- F.Mask (top solder mask), thickness ~0.01 mm, Er ~3.3
- F.Cu 0.035 mm
- Dielectric 1 (prepreg) 0.10 mm FR4, Er ~4.5
- In1.Cu 0.017 mm
- Dielectric 2 (core) 1.19 mm FR4, Er ~4.5
- In2.Cu 0.017 mm
- Dielectric 3 (prepreg) 0.10 mm FR4, Er ~4.5
- B.Cu 0.070 mm
- B.Mask (bottom solder mask) 0.035 mm, Er ~3.3
- B.Paste
- B.Silkscreen (bottom)
- Finish: HAL lead-free

## 4) Key components (why chosen)
- Controller: LM5122-Q1 synchronous boost controller, automotive-grade, wide VIN, forced-CCM option for stable motor loads.
- Primary FETs: CSD18540Q5B 60 V NexFET, low Rds(on) (~3.3 mΩ typ) for high current and efficiency.
- Inductor: SER2918H 22 µH power inductor with low DCR, sized for the 10 A, 36 V target.
- Sense resistor: 2 mΩ (2512) to set current limit and monitor power stage stress.
- Output bulk: multiple 470 µF electrolytics plus polymer/tantalum to manage surge and ripple on the 36 V bus.
- Decoupling: ceramic caps at VIN/VCC/CS pins to keep loop impedance low; place tight to pins to control switching edges.
- Thermal/conducted heat: pour VOUT/SW/VIN on all layers and stitch with vias near FETs/diodes/inductor to spread loss; keep short, wide planes for SW to control ringing.

## 5) Interfaces and connectors
- Input power connector.
- Output power connector.
- Sense/enable/test as per schematic.

## 6) Files included
- Gerbers (RS-274X)  
- NC drill files  
- `BOM.csv` — JLCPCB-compatible  
- `CPL.csv` — pick-and-place (top side only)

## 7) Design reference (WEBENCH®, approximate simulation values)
- Tool: TI WEBENCH; device LM5122QMH/NOPB; target 18–24 V in → 36 V @ 10 A; created 2026-01-17.
- Major simulated values (approximate; some resistors may be split series/parallel; mΩ values are rough):
  - L1: 22 µH, ~2.95 mΩ
  - Cin: ~39 µF, ~30 mΩ
  - Cout: ~56 µF each, ~30 mΩ, Qty 10
  - Coutx: 47 µF, ~16.6 mΩ
  - Rsense: ~2 mΩ, 1 W
  - Rfbt/Rfbb: ~46.4 kΩ / ~1.6 kΩ
  - UVLO: Ruvt ~49.9 kΩ / Ruvb ~4.22 kΩ
  - Timing/comp: Rt ~43.2 kΩ, Rslope ~392 kΩ, Ccomp ~220 nF, Ccomp2 ~3.9 nF, Cvcc ~10 µF, Css ~27 nF, Cbst ~1 µF, Cres ~470 nF, Dbst VF@Io ~950 mV, VRRM ~150 V
  - MOSFETs: M1/M2 ~60 V, ~200 A class (Qty 2 each per simulation)
- Note: verify divider/sense and mΩ parts against actual BOM and any series/parallel splits before ordering/assembling.

## 8) Assembly notes (important)
- High-current copper pours — do not reduce copper weight.
- Through-hole polymer capacitors used for bulk output filtering.
- Ensure polarity for input/output bulk capacitors and bootstrap diode.
- Inductor is magnetically shielded; GND plane under inductor is intentional.
- Cleaning: remove flux residue, especially around FB, COMP, CSP/CSN, VIN pins; avoid conductive residue near SW node.

## 9) Bring-up procedure
1) Current-limited power-up: bench supply 0.5–1.0 A limit; VIN = 18 V; no load on VOUT.  
2) Idle check: VOUT to ~36 V; input current in tens of mA; no audible noise/heating.  
3) Increase input current limit gradually: 2 A → 5 A → 10 A; monitor VOUT stability, MOSFET/inductor temperature, ripple/oscillation.  
4) Apply load: start resistive/e-load; avoid motors first power-up; verify regulation before dynamic loads.

## 10) Expected idle measurements (no load)
- VIN current: ~20–60 mA (depends on switching frequency).
- VOUT ripple: low, stable.
- Thermals: no hotspots.

## 11) Warnings / limits
- Board can source very high current — treat as a power device.
- Do not hot-plug loads during early testing.
- Ensure adequate airflow during high-power operation.

## 12) Notes
- Layout relies on tight SW loops and proper ground referencing.
- Any change to FB divider or compensation requires re-validation.

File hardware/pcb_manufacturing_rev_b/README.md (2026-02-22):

# Arduino Rover Main PCB — Rev B

> DEPRECATED REVISION: For new work, start at `../current/main_pcb/README.md`.

**Scope:** Rationale, constraints, and implementation notes for the Arduino-based rover PCB that distributes power/signals to motors, servos, LiDAR, sensors, and a Raspberry Pi rail.

**Owner / Contact:** Tim Wang — timwang007@outlook.com  
**Revision:** Rev B  
**Date:** 2025-12-29

## 1) Overview
Through-hole, module-friendly PCB that routes power (including high-current 5 V rails), breaks out signals via headers, and supports multiple actuators/sensors. Built around off-the-shelf parts to keep first-time assembly reliable and repairable without a reflow oven. Rev B incorporates the capacitor polarity/footprint/silkscreen corrections from Rev A.

## 2) Design goals and constraints
- Easy assembly with basic soldering (THT-only).
- Robust 5 V power delivery for multiple servos and a Raspberry Pi rail.
- Low-noise returns via continuous ground planes.
- Modular pin headers for expansion and quick swaps.
- Tradeoff: larger board area because of THT and modules; SMD could shrink size but increases assembly complexity.

## 3) System architecture
- 2x Arduino boards (servo pin count is high; first Arduino already heavily used).
- 4x servo motors: two for broom, one for flag, one for optional mechanism.
- LiDAR and other sensors (logic-level domain).
- Raspberry Pi 5 V rail (high-current domain).

## 4) Component choices
- THT everywhere for hand assembly/rework.
- Servo motor: MG996R (stall torque ~9.4 kg·cm @ 4.8 V).
- Three 5 A buck converters:
  - Servo rail
  - LiDAR + second Arduino rail
  - Raspberry Pi rail  
  Note: “5 A” is regulator rating; usable current depends on VIN, thermals, airflow, and copper area.
- Decoupling/bulk: 0.1 µF at device pins; 220 µF + 2200 µF on rails to handle servo/Pi transients; place close to loads.
- Thermal strategy: pour rails on all layers where possible and via-stitch near connectors/bucks to spread heat and reduce drop.

## 5) Power architecture
- Bulk storage: 2200 µF near the source for low-frequency ripple/large steps.
- Per-rail decoupling: 220 µF + 0.1 µF at loads to handle transients and high-frequency noise.
- Servo spikes can brown out logic: place bulk caps close to servo rail and Pi rail; keep sensor/logic decoupling close to modules.

## 6) PCB stack-up and grounding
- Layer stack (Rev B — produced):
  - F.Silkscreen (top)
  - F.Paste
  - F.Mask (top solder mask), thickness ~0.01 mm, Er ~3.3
  - F.Cu 0.035 mm
  - Dielectric 1 (prepreg) 0.10 mm FR4, Er ~4.5
  - In1.Cu 0.017 mm
  - Dielectric 2 (core) 1.19 mm FR4, Er ~4.5
  - In2.Cu 0.017 mm
  - Dielectric 3 (prepreg) 0.10 mm FR4, Er ~4.5
  - B.Cu 0.070 mm
  - B.Mask (bottom solder mask) 0.035 mm, Er ~3.3
  - B.Paste
  - B.Silkscreen (bottom)
  - Finish: HAL lead-free
- Grounding guidance: avoid splitting planes unless justified; keep high-current motor returns away from sensitive sensor returns.

## 7) Routing rules (tracks, vias, current intent)
- Track widths: signals at 1.0 mm; power at 2.0 mm.
- Vias: signals 1.2/0.6 mm; power 1.6/0.8 mm.
- Apply wider copper, shorter runs, and multiple vias in parallel on high-current rails (servo, Pi).

## 8) Decoupling, bulk capacitance, noise control
- 0.1 µF as close as possible to device power pins.
- 220/2200 µF near rail entry points and high-transient loads.
- Servo noise containment: short high-current paths, tight return loops, and avoid routing servo returns under sensitive sensor lines.
- Optional: extra bulk caps on servo rail; ferrite bead or LC filtering for sensor rail.

## 9) Protection and safety
- Fuse on main input for overcurrent protection.
- Reverse-polarity protection evaluated but not stuffed (XT30 connector reduces risk); consider an optional footprint/jumper to enable later without a respin.

## 10) Connectors, headers, expandability
- Pin headers for servos, LiDAR, sensors, and Pi power. Label with signal, voltage, ground, and pin-1 orientation where possible for assembly clarity.

## 11) Assembly and bring-up checklist
- Before soldering: run ERC/DRC with fab rules; confirm connector footprints/orientation (XT30, headers).
- Power-up sequence (recommended):
  1) Current-limited bench supply.
  2) Verify each buck rail with no load.
  3) Add loads gradually: Arduino → sensors → servos → Pi rail.
  4) Watch droop/ripple during servo movement.
- Quick checks: fuse rating vs peak currents; no unexpected heating on bucks, high-current pours, and connectors.

## 12) Known issues and documentation notes
- Schematic digital nets were mislabeled (all “DIGI”). Should be unique (DIGI1, DIGI2, ...). Correct labels in schematic/PCB before next spin.

## 13) Future improvements
- PMOS selection (placeholder): when selecting an ideal-diode/reverse-protection device, specify VDS margin, ID/power dissipation, RDS(on) at gate drive, thermal, and gate protection.
- Optional reverse-polarity protection footprint (even if bypassed by default).
- Current-shunt footprint for debugging servo/Pi current draw.

## 14) Design rationale (summary)
THT + modules maximize assembly success and reworkability. A 4-layer stack with continuous ground planes lowers return-path impedance and noise. Routing uses 1.0 mm / 2.0 mm tracks and 1.2/0.6 mm / 1.6/0.8 mm vias, with wider copper, shorter runs, and via arrays on high-current paths. Bulk and decoupling capacitance supports transient-heavy loads; a fuse provides basic overcurrent safety. Known net-label issues are flagged for correction.

## 15) Post-manufacture testing / revisions
- Rev B: incorporates the capacitor polarity/footprint/silkscreen corrections from Rev A; no additional errata noted yet. Use the same bring-up sequence and monitor rails for any remaining issues.

## 16) Rev C planned stack-up (not fabricated yet)
- Layer stack (target for Rev C):
  - F.Silkscreen (top silk screen), color/material not specified
  - F.Paste (top solder paste)
  - F.Mask (top solder mask), thickness 0.01 mm, color not specified, material not specified, Er 3.3, LossTg 0
  - F.Cu 0.035 mm
  - Dielectric 1 (prepreg) 0.10 mm FR4, Er 4.5, LossTg 0.02
  - In1.Cu 0.017 mm
  - Dielectric 2 (core) 1.25 mm FR4, Er 4.5, LossTg 0.02
  - In2.Cu 0.017 mm
  - Dielectric 3 (prepreg) 0.10 mm FR4, Er 4.5, LossTg 0.02
  - B.Cu 0.035 mm
  - B.Mask (bottom solder mask) 0.035 mm, color not specified, material not specified, Er 3.3, LossTg 0
  - B.Paste (bottom solder paste)
  - B.Silkscreen (bottom silk screen), color/material not specified
  - Finish: HAL lead-free

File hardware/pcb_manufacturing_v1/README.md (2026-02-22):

# Arduino Rover Main PCB - V1 (Archived)

This is a legacy main PCB revision retained for historical reference.

For new work, start at `../current/main_pcb/README.md`.

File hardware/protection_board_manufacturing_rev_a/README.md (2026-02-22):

# Power Protection Board — Rev A

> DEPRECATED REVISION: For new work, start at `../current/protection_board/README.md`.

**Project:** Power Protection Board  
**Owner / Contact:** Tim Wang — timwang007@outlook.com  
**Revision:** Rev A  
**Date:** 2026-01-23

## 1) Overview
Primary power-entry protection board for a battery system. Originally documented for 24 V (6S), but the deployed use is a 5S pack (≈18.5 V nominal). Functions: reverse polarity protection (ideal diode), hot-plug/inrush control, adjustable current limit and circuit breaker, UVLO/OVLO, Power-Good (PGD) status, and surge/transient suppression. Targeted at robotics/rover/battery systems with high inrush loads.

## 2) Key ICs and architecture
- Power path: LM74700-Q1 (ideal diode/reverse battery) → LM5069 (hot-swap controller with dv/dt ramp, current limit, fault timer) → external pass MOSFETs in parallel.
- Protection elements: TVS on VIN; sense resistor for current limiting; dv/dt startup network; bulk + ceramic caps on VIN and VOUT.

## 3) Electrical specifications
- Input voltage: 6S battery (~18–25.2 V nominal); max transient clamped by TVS.
- Current limit: ~20 A (configurable via RSNS).
- Fault timer: ~320 ms.
- Startup: controlled dv/dt.
- MOSFETs: 2–3 devices in parallel.
- Operating temp: automotive-grade components.

## 4) PCB stackup (all boards)
- F.Silkscreen (top)
- F.Paste
- F.Mask (top solder mask), thickness ~0.01 mm, Er ~3.3
- F.Cu 0.035 mm
- Dielectric 1 (prepreg) 0.10 mm FR4, Er ~4.5
- In1.Cu 0.017 mm
- Dielectric 2 (core) 1.19 mm FR4, Er ~4.5
- In2.Cu 0.017 mm
- Dielectric 3 (prepreg) 0.10 mm FR4, Er ~4.5
- B.Cu 0.070 mm
- B.Mask (bottom solder mask) 0.035 mm, Er ~3.3
- B.Paste
- B.Silkscreen (bottom)
- Finish: HAL lead-free

## 5) Interfaces and signals
- J1 — VIN (input): Battery + / GND; protected by TVS + LM74700-Q1.
- J2 — VOUT (output): Protected, current-limited output to system.
- PGD (Power-Good): open-drain; pulled up to logic rail (3.3 V / 5 V). LOW = fault/startup; HIGH = power stable. Recommended for MCU enable gating, PG LED, system fault monitoring.

## 6) Key components (design intent)
- LM74700-Q1: ideal diode controller for reverse polarity, minimizes forward drop and turn-on stress.
- LM5069-2: hot-swap / inrush controller with adjustable dv/dt, current limit, and fault timer; suited for 10–80 V systems.
- Pass FETs: CSD19536KTT 100 V NexFET devices in parallel; low Rds(on) for reduced dissipation at ~20 A limits.
- TVS: SMBJ33A class (VIN → GND) for surge/transient clamping.
- Sense resistor: 5 mΩ (2512) network for setting ~20 A current limit.
- VCAP (LM74700): 1 µF X7R (mandatory).
- dv/dt cap: ~147–150 nF ceramic.
- Bulk caps: VIN electrolytic + ceramic; VOUT electrolytic bulk + ceramic bypass.
- Gate resistors: per MOSFET (~10 Ω).
- Decoupling/thermal: place ceramics tight to device pins; pour VIN/VOUT/GND on all layers and via-stitch near FETs/sense resistor/TVS to spread heat and lower impedance.

## 7) Files included
- `Gerber/` + `Gerber.zip`
- `BOM.csv`
- `CPL.csv`
- TODO: fabrication drawing/stackup, assembly drawings (top/bottom with polarity), units/origin note for PnP, DNP/variants list, schematic/layout PDF.

## 8) Build notes (important)
- Place TVS and VIN bulk caps close to the input connector.
- Keep sense resistor Kelvin connections clean.
- Match copper/thermal layout for parallel MOSFETs.
- Keep dv/dt network close to LM5069.
- Verify pin-1 orientation for all SOT-23 devices.

## 9) Bring-up / test procedure
1) Power with a current-limited bench supply.  
2) Verify no reverse-polarity conduction.  
3) Observe controlled VOUT ramp; PGD transitions LOW → HIGH when stable.  
4) Briefly short VOUT: confirm current limit and fault timeout/latch/retry behavior.  
5) Connect real load only after PGD is stable.  

## 10) Constraints / notes
- PGD requires a logic rail (3.3 V or 5 V pull-up).
- MOSFET SOA depends on ILIM, fault time, and number of parallel devices.
- Long battery leads may require higher-power TVS.

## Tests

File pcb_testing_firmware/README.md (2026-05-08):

# PCB Testing Firmware

This folder contains Arduino sketches, diagnostics, handoff notes, and references used for PCB testing and electronics bring-up. It is not the final rover software.

## Current structure
- `2026/controllers/` - Final-stack board validation sketches.
- `2026/docs/` - Board validation handoff notes for pin maps, power control, actuators, and test flow.
- `2025/controllers/` - Earlier Arduino Nano Every testing sketches.
- `2025/diagnostics/` - Isolated bench tests grouped by subsystem:
  - `drivetrain/`
  - `link/`
  - `servos/`
- `2025/docs/` - Firmware-facing notes for PCB testing.
- `2025/references/` - Datasheets and component notes used by bring-up sketches.
- `archive/2024_code/` - Legacy Arduino and Raspberry Pi experiments kept for reference.

## Notes
- Use this folder when validating boards, pin maps, drivers, servos, or power-control behavior.
- Put future rover software in `../firmware/`, not here.
- A SHA-256 content check was previously run across the testing firmware files; no duplicate file contents were found at that time.

## Path migration map
- `firmware/2025/` -> `pcb_testing_firmware/2025/`
- `firmware/2026/` -> `pcb_testing_firmware/2026/`
- `firmware/archive/2024_code/` -> `pcb_testing_firmware/archive/2024_code/`

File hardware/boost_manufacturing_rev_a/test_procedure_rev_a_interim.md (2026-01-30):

# Boost Converter — Rev A (Interim Test Plan)
## Scenario
Bench-test Rev A after removing C1 and swapping C2/C7 to higher-voltage parts (no added input caps C12/C13/C14). Goal: verify safe operation before respinning Rev B.

## 0) Prep
- Remove C1 (47 µF, 10 V). Leave pads open.
- Swap C2 and C7 to available 50 V parts (per Rev B: C13967 and C5378). Keep all other parts as Rev A.
- Tools: bench supply 0–30 V / ≥10 A with current limit, DMM, scope, 1–2 Ω / 200 W load or e-load, shorting bar for brief tests.
- Wiring: short, thick leads; sense leads on VIN if available.

## 1) Visual / Continuity
1. Inspect swapped caps for correct polarity and clearance; ensure removed C1 pads are clean (no solder balls).
2. DMM continuity: VIN+ to GND open; VOUT+ to GND open; VIN+ to VOUT+ shows body-diode path only (no hard short).

## 2) Cold Power-Up (no load)
1. Set VIN = 18 V, ILIM = 0.5 A. No load connected.
2. Enable supply. Expected: VOUT ramps to ~36 V (regulated). Input current tens of mA. No overshoot >1 V.
3. If current-limit hits or VOUT collapses, power off and inspect swaps.

## 3) Soft-Start / Waveform Capture
1. VIN = 20 V, ILIM = 2 A. Scope CH1 on VOUT, CH2 on VIN.
2. Enable. Confirm clean ramp to 36 V, minimal ringing. Record rise time and any overshoot.

## 4) Light Load
1. Apply ~1 A load at 36 V (≈36 Ω or e-load CC). ILIM = 3 A.
2. Check VOUT regulation (±2%) and ripple. MOSFETs/inductor cool to mild warm.

## 5) Moderate Load
1. Increase load to ~5 A at 36 V. ILIM = 8–10 A.
2. Monitor VOUT droop, ripple, and temperatures for 60–120 s. Acceptable: VOUT within spec, no audible instability, temps under ~80 °C case (brief touch/IR).

## 6) Line Sweep
1. Hold load at ~2–3 A. Sweep VIN: 18 V → 22 V → 25 V in steps.
2. Confirm stable regulation, no hiccup/skip. Note any audible change.

## 7) Fault / Overcurrent Check (short tap)
1. No load. VIN = 20 V, ILIM = 8–10 A.
2. Briefly tap VOUT to GND (<0.5 s). Expect current limit then controller hiccup/restart; no damage or latch-up. Allow cool-down afterward.

## 8) Extended Dwell
1. Run 3–4 A load at 36 V for 10 minutes (VIN = 20–22 V). Watch temps on FETs, diode, inductor, sense resistor. Stop if discoloration or >90 °C case.

## 9) Post-Test
- Recheck continuity, look for discoloration or vented caps.
- Log: VIN, VOUT, load currents, ripple, temps, any anomalies during sweep/short.

## Pass/Fail Quick Criteria
- Starts cleanly at 18–22 V with no load.
- Holds 36 V within tolerance at 1–5 A loads without oscillation.
- Survives brief output short without damage.
- Thermal rise acceptable under 5 A for short runs and 3–4 A for 10 min dwell.

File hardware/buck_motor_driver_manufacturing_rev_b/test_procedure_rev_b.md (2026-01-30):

# Buck Converter + Motor Driver — Rev B
## Bench Test Procedure

Rev B changes are confined to the buck BOM (value corrections and cost-down parts). Motor driver stage is unchanged from Rev A. Test the buck section first; then optionally exercise the motor driver using the same sketches as Rev A.

### 0) Equipment
- Bench supply 0–30 V / ≥10 A with current limit (start low).
- DMM; oscilloscope for ripple/soft-start.
- Electronic load or resistors for 5 V at 0.5–10 A (2.5 Ω/25 W, 1 Ω/50 W, 0.5 Ω/50–75 W). Keep high-current runs short.
- USB cable for Arduino Nano Every if you want to test motor driver sketches later.

### 1) Visual / Continuity
1. Confirm Rev B MPN swaps populated (R2/R3/R4/R5/R8/R20, C8/C13/C14/C17, cost-down caps/diode) and R19 removed, C19/C20 removed.
2. DMM: VIN–GND open; VOUT–GND open; VIN–VOUT open (no short).

### 2) UVLO / Soft-Start (buck)
1. No load. Set VIN = 6 V, ILIM = 0.5 A. Ramp up slowly and note UVLO turn-on; then ramp down to find turn-off. Record both.
2. VIN = 12 V, ILIM = 1 A. Scope VOUT to measure soft-start (target few ms, no overshoot). Verify VOUT ≈5.0 V ±1%.

### 3) Switching Frequency
- SYNC tied to VCC (free-run). Measure SW node frequency; expect ~250 kHz (set by RRT). Verify regulation holds.

### 4) Light Load
1. Apply 0.5 A load (≈10 Ω). ILIM = 2 A.
2. Check VOUT regulation and ripple (<80 mVpp). Components should remain cool.

### 5) Mid Load
1. Step load to 2 A, 4 A, 6 A. Raise ILIM to 8 A.
2. At each step, log VOUT and ripple; stop if droop >150 mV or temps >80 °C case.

### 6) High Load (short duration)
1. VIN = 24 V. Load 8–10 A for ≤30 s, then 12 A for ≤15 s. ILIM 12–15 A.
2. Pass if VOUT stays within tolerance and no audible instability; stop if heating rises quickly.

### 7) Line Sweep
1. Hold 3–4 A load. Sweep VIN: 12 V → 18 V → 24 V → 28 V (do not exceed lowest-rated component). Confirm stable regulation and ripple.

### 8) Load Transient (if e-load supports)
1. VIN = 24 V. Program 1 A ↔ 6 A step at ~1 kHz. Capture VOUT deviation; aim for <100 mV peak and fast recovery without ringing.

### 9) Motor Driver Smoke Test (optional, unchanged hardware)
1. Connect Arduino, load `motor_driver_test.ino` (Rev A folder) with pins: ENA D10, ENB D9, INA D8, INB D7, PWM D5, CS A0.
2. Use low duty to verify forward/reverse/brake; monitor buck rail for droop during motor pulses.

### 10) Post-Test
- Power down, discharge caps, inspect for heat discoloration.
- Log UVLO, soft-start time, frequency, VOUT vs load, transient results, temps.

### Pass/Fail (quick)
- UVLO/soft-start clean; VOUT ≈5 V, no overshoot.
- Stable regulation through 0.5–6 A continuous and short 10–12 A bursts without oscillation.
- Acceptable ripple and thermals; no component damage.
- Motor driver stage powers and drives at low duty without browning the buck rail.

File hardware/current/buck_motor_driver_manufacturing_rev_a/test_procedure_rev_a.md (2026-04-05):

# Buck Converter on Buck + Motor Driver Board - Rev A

This is a short bench check for the buck stage only. Stay below the lowest-rated part on your build.

## Equipment
- Bench supply, up to your board rating, with current limit
- DMM and scope
- Load for 5 V, 0.5-12 A

## Quick Test
1. Unpowered: inspect the controller, bootstrap parts, inductor, and feedback network. Confirm VIN to GND, VOUT to GND, and VIN to VOUT are not shorted.
2. UVLO and startup: with no load, ramp VIN from 6 V and record where the rail turns on and off. Then test at 12 V and confirm VOUT = 5.0 V +/-1% with a soft-start around 6 ms and no meaningful overshoot.
3. Frequency: SYNC is tied to VCC on this board, so the converter should free-run at about 250 kHz.
4. Load: test 0.5 A, then step up to 2 A, 4 A, and 6 A. If stable, do short checks at 8 A, 10 A, and 12 A with 24 V input. Stop for droop above about 150 mV, instability, or case temperatures above about 80-90 C.
5. Line check: if the fitted parts are rated for it, repeat the regulation check at 24 V, 36 V, and 48 V input.
6. Optional transient: at 24 V, step 1 A to 6 A and back. Aim for less than about 100 mV deviation.

## Pass
- Clean startup and correct 5 V output
- Stable operation through the tested load range
- About 250 kHz switching with no hiccup or oscillation
- Thermals stay reasonable during short high-load runs

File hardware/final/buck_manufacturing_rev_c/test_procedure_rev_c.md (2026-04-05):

# Buck Converter - Rev C

Short bench check for the 5 V buck-only board. Focus on the corrected 5.0 V trim, parallel MOSFETs, gate resistors, and snubber.

## Equipment
- Bench supply, 0-30 V, with current limit
- DMM and scope
- Load for 5 V, 0.5-12 A

## Quick Test
1. Unpowered: verify R9 = 22.6 kOhm, R10 = 2 Ohm, R11 = 1 Ohm, C24 = 1 nF, R14/R15 = 2 Ohm, the extra MOSFETs are fitted correctly, and there is no short from VIN to GND, VOUT to GND, or VIN to VOUT.
2. Startup: no load, ramp VIN from 6 V with 0.5 A limit and note UVLO on/off. Then test at 12 V / 1 A and confirm clean soft-start with VOUT = 5.00 V +/-1%.
3. Switching: check the SW frequency. Target is about 250 kHz. The red LED should be on while power is bad or starting, and off once power-good is reached.
4. Load: test 0.5 A, then 2 A, 4 A, and 6 A. Pass if VOUT stays in spec, ripple stays reasonable, and case temperature stays below about 80 C.
5. Short stress: at 24 V, run 8-10 A for up to 30 s and 12 A for up to 15 s only if thermals look safe. Stop for fast heating, large droop, or audible instability.
6. Optional sweep: hold 3-4 A and sweep VIN through 12 V, 18 V, 24 V, and 28 V. Regulation should stay stable.

## Pass
- Clean UVLO and soft-start
- VOUT stays near 5 V through normal load
- No oscillation, severe ringing, or obvious MOSFET current-sharing imbalance
- No visible damage or overheating after test

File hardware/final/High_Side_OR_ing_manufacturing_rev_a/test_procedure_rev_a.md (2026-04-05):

# LM5050 Redundant Supply Board - Rev A

Short validation for the high-side OR-ing board that picks between 18 V and 36 V inputs.

## Equipment
- Two current-limited bench supplies
- DMM, and a scope if you want switchover captures
- Light to moderate load

## Quick Test
1. Unpowered: inspect the LM5050, MOSFETs, and connector polarity. Confirm VIN_18, VIN_36, and VOUT are not shorted to GND or to each other.
2. Single-source check: power the 18 V input alone, then the 36 V input alone. In both cases VOUT should follow the active source and hold a light load.
3. Priority check: turn both sources on at 18 V and 36 V. The 36 V path should carry the load and the 18 V path should sit near zero current.
4. Switchover: with both sources active and a moderate load, turn 36 V off and back on. VOUT should transfer cleanly to 18 V and then back to 36 V.
5. Reverse blocking: with only one input active, confirm the inactive input does not get back-fed beyond normal leakage.
6. Load sweep: step the load upward until the expected operating current. Stop for thermal issues or unstable output.

## Pass
- Both inputs work by themselves
- The higher rail wins when both are present
- Switchover is repeatable and clean
- Reverse current into the inactive source stays low

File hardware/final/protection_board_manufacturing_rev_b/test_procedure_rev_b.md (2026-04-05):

# Power Protection Board - Rev B

Short validation for the 5S-tuned protection board. Rev B targets a 5S pack with UVLO around 15-16 V and OVLO around 22.5-23.0 V.

## Equipment
- Bench supply, 0-30 V, with current limit
- DMM and scope
- 3 A load or electronic load
- PGD pull-up to 3.3 V or 5 V

## Quick Test
1. Unpowered: inspect the SOT-23 parts, TVS, sense resistor, and charge-pump capacitor. Confirm ANODE and VCAP are not shorted, and there is no short on VIN+, VOUT+, or PGD.
2. Normal startup: at 18.5 V / 0.5 A with no load, VOUT should ramp up to VIN and PGD should go high once stable.
3. Reverse polarity: briefly apply 12 V with reversed leads. Current should stay near zero, VOUT should stay near 0 V, and PGD should stay low.
4. Load test: at 20 V, apply about 3 A. VOUT should stay close to VIN, PGD should stay high, and temperatures should stay reasonable.
5. Fault test: at 20 V, briefly short VOUT to GND for less than 0.5 s. The board should current-limit, fault, and recover after a power cycle or EN toggle.
6. Threshold check: slowly sweep VIN and record UVLO and OVLO. Targets are about 15-16 V rising for UVLO and about 22.5-23.0 V for OVLO, with a little hysteresis.
7. Optional hot-plug and dwell: hot-plug at 20-23 V and run 2-3 A for 10 minutes. The ramp should stay controlled and PGD should not chatter.

## Pass
- Reverse polarity is blocked
- Startup ramp is clean and PGD behaves correctly
- Board carries about 3 A without excessive droop or heat
- Current limit trips and the board recovers normally

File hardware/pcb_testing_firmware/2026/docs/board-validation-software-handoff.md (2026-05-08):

# PCB Testing Software Handoff - 2026

Software-facing notes for validating the Microver 2026 final compute and control boards. These sketches are for PCB testing and electronics bring-up, not the final rover software stack.

## Control stack
- High-level control can run on the Raspberry Pi.
- Low-level drive and actuator bring-up uses Arduino Nano Every sketches in `../controllers/`.
- The final dual-Arduino compute board mates to the final control board through the `Left` and `Right` interconnects.
- Power and actuator details live in `power-and-actuator-control-handoff.md`.

## Final control-board drive pin map
The 2026 both-sides drive test uses this Arduino Nano Every pin map.

| Drive side | PWM | INA | INB | ENA/DIAGA | ENB/DIAGB | CS |
| --- | --- | --- | --- | --- | --- | --- |
| Left, Drive 4-6 | D10 | D6 | D7 | A6 | A7 | A0 |
| Right, Drive 1-3 | D9 | D4 | D5 | D8 | D13 | A1 |

## Bring-up sketches
- `../controllers/simple_motor_test/simple_motor_test.ino` - Minimal single-driver motor test.
- `../controllers/minimum_one_wheel_test/minimum_one_wheel_test.ino` - Minimal one-wheel test.
- `../controllers/one_side_spin_test/one_side_spin_test.ino` - One-side drivetrain spin test.
- `../controllers/both_sides_drive_test/both_sides_drive_test.ino` - Both-sides drive test.

## Serial controls
The both-sides drive test uses `115200` baud.

| Command | Behavior |
| --- | --- |
| `f` | Run both sides forward for the configured test duration. |
| `r` | Run both sides reverse for the configured test duration. |
| `s` | Stop immediately. |
| `d` | Print driver diagnostics and current-sense ADC values. |
| `+` | Increase test speed. |
| `-` | Decrease test speed. |

## Validation flow
1. Lift or unload the rover before first motor tests.
2. Confirm the final compute board is oriented correctly on the final control board.
3. Start with `simple_motor_test`, then move to one-wheel and one-side tests.
4. Use `both_sides_drive_test` only after each side has been validated independently.
5. Watch `ENA/DIAGA`, `ENB/DIAGB`, and current-sense readings during every drive test.
6. Keep unused actuator outputs disabled unless hardware is installed.

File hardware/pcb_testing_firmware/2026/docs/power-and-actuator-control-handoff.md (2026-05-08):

# Power and Actuator Control Handoff

## System Overview

The rover has six drive wheels. The wheels are split into two sides, with one
motor controller driving the three wheels on the left side and one motor
controller driving the three wheels on the right side.

The final control board has four servo motor positions, but the current rover
uses only three of them. Leave the unused servo output disabled in software
unless a fourth actuator is installed later.

The rover also uses a camera for object detection and LiDAR for object
avoidance. High-level software uses those sensors to decide where the rover
goes, while the low-level firmware handles the motor and actuator outputs.

## Final Control Board Functions

| Function | Software responsibility |
| --- | --- |
| Boost enable | Drive the boost-control GPIO. |
| Left/right drive channels | Generate direction and PWM for two H-bridge channels. |
| Six wheel encoders | Count quadrature signals for per-wheel feedback. |
| Driver diagnostic pins | Read enable/fault state from the motor drivers. |
| Current sense | Read analog current feedback from the motor drivers. |
| Servo outputs | Generate servo pulses for installed actuators. |

Each rover side has one drive channel. Three wheel motors are connected to each
side's drive channel:

| Drive group | Physical motors |
| --- | --- |
| Drive 1-3 / right channel | `Drive_1`, `Drive_2`, `Drive_3` |
| Drive 4-6 / left channel | `Drive_4`, `Drive_5`, `Drive_6` |

The motors on one side receive the same H-bridge output, but each wheel still has
its own encoder input. Software can therefore command by side and monitor by
wheel.

## Boost Control

Firmware owns one boost-control signal exposed as `on/off_Boost`.

| Compute board | Boost-control pin |
| --- | --- |
| STM32 compute board | `PC10` / `BOOST_EN` / `TP15` |

## Drive Motor Control

Each rover side uses one VNH5019A-E H-bridge:

| Software channel | Board signal group | Physical drive connectors |
| --- | --- | --- |
| Right drive | `DRV1_*` signals | `Drive_1`, `Drive_2`, `Drive_3` |
| Left drive | `DRV2_*` signals | `Drive_4`, `Drive_5`, `Drive_6` |

VNH5019A-E control table from the datasheet:

| Command | `INA` | `INB` | `PWM` | Behavior |
| --- | --- | --- | --- | --- |
| Stop / brake low | `0` | `0` | `1` | Both outputs low. |
| Clockwise | `1` | `0` | duty | `OUTA` high, `OUTB` low when PWM is high. |
| Counterclockwise | `0` | `1` | duty | `OUTA` low, `OUTB` high when PWM is high. |
| Brake high | `1` | `1` | `1` | Both outputs high. |
| PWM off | any | any | `0` | Low-side switches off. |

Firmware notes:

- Use `INA` and `INB` for direction.
- Use `PWM` for speed; the datasheet allows PWM up to `20 kHz`.
- Keep `ENA/DIAGA` and `ENB/DIAGB` high for normal use. If either reads low,
  the driver is reporting a fault.
- `CS` outputs motor-current feedback when current sense is enabled.

## Servo Outputs

The final control board has four servo-style outputs.

| Header | Signal |
| --- | --- |
| `J24` / Servo 1 | `SERVO1_PWM` |
| `J25` / Servo 2 | `SERVO2_PWM` |
| `J26` / Servo 3 | `SERVO3_PWM` |
| `J27` / Servo 4 | `SERVO4_PWM` |

The current rover uses three of the four servo outputs. The fourth output is
unused.

Brushless DC ESCs use the same RC-servo-style signal: the ESC reads pulse width,
not the off-time. Typical values are `1000 us` for zero throttle, `1500 us` for
midpoint, and `2000 us` for maximum throttle.

ESC calibration is needed so the ESC learns this controller's minimum and
maximum throttle pulse widths. Calibration is not the same as arming:

- Calibration is usually done once: send `2000 us`, power the ESC, wait for the
  calibration beeps, then send `1000 us`.
- Arming happens every startup: send `1000 us` for about `2` to `5` seconds so
  the ESC accepts that throttle is safely at zero.

Software should not send a run command immediately after power-up. Keep sending
`1000 us` during the arming wait. A non-blocking `millis()` timer is preferred so
the controller can still read safety inputs while waiting.

For first fan tests, use a very low run value because current can rise quickly if
the fan spins too fast. Start near `1050 us` to `1100 us`, and only increase if
the motor does not spin smoothly.

## Bring-Up Checklist

1. Boot firmware with the rover lifted and all drive commands disabled.
2. Confirm each motor-driver diagnostic pin reads healthy when enabled.
3. Send low PWM to one drive side and verify wheel direction.
4. Repeat for the other drive side.
5. Verify each installed servo output.
6. Arm the brushless ESC at `1000 us` before sending any run command.
7. Start brushless fan tests near `1050 us` to `1100 us`.
8. Leave unused actuator outputs disabled in software.

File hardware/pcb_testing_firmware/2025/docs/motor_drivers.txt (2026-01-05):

- Pins D5 and D6 connect to three motor drivers that all operate identically.
- Pins D9 and D10 connect to a different set of three motor drivers that also operate identically.
- Encoder 1 uses pins D16 and D17.
- Encoder 2 uses pins D14 and D15.
- Encoder 3 uses pins D20 and D21.
- Encoder 4 uses pins D18 and D19.
- Rover has three wheels per side; turning by running sides opposite directions.
- Only two motors per side have encoders, hence 4 encoders for 6 motor drivers.
- Arduino Every 1 handles the six motor drivers and four encoders described above.
- Arduino Every 2 controls four servo motors: D10 -> Servo 4, D9 -> Servo 3, D6 -> Servo 2, D5 -> Servo 1.

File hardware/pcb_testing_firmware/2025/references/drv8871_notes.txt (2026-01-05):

Adafruit DRV8871 Motor Driver Notes
-----------------------------------
- Brushed DC H-bridge rated for 6.5V–45V motor supply; logic pins tolerate up to 5.5V, so Nano Every pins can drive IN1/IN2 directly.
- Typical Rds(on) (high + low) is ~565 mΩ; driver can source/sink up to ~3.6 A peak before current limiting and thermal shutdown intervene.
- Current limit is set by resistor Rlim. Board ships with ~30 kΩ installed, yielding roughly a 2 A limit; replace or piggyback different resistors to change the limit.
- IN1 drives OUT1 and IN2 drives OUT2. Apply complementary PWM or static logic combinations to control the H-bridge:
  * IN1=LOW, PWM on IN2 => forward drive (OUT1 low, OUT2 PWM high).
  * IN2=LOW, PWM on IN1 => reverse drive.
  * IN1=IN2=LOW => motor brake (both low).
  * IN1=IN2=HIGH => brake/high-side short (avoid unless needed).
- PWM up to ~200 kHz is supported, but lower frequencies (e.g., 20 kHz) are more efficient and easier on the microcontroller timers.
- Driver integrates UVLO, overcurrent protection, and thermal shutdown, so faults automatically disable outputs until safe.
- Logic power is derived internally from VMotor; no separate 5V supply required other than the control logic source.
- Use thick wires and solid solder joints on VMotor, GND, and OUT terminals to minimize wiring losses.
- Board ships with screw terminals and header strips; ensure terminal openings face outward before soldering.
Useful for firmware
-------------------
- Treat driver as two GPIO/PWM pins per motor. For six motors on Arduino Every 1, map D5/D6 and D9/D10 accordingly and reuse the same control macros/functions.
- Implement per-motor current-limit awareness: expect ~2 A cap unless hardware resistor changed.
- Provide initialization that sets both inputs LOW before enabling PWM to avoid startup kicks.

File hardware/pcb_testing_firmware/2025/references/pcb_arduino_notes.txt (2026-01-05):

Arduino Rover PCB Notes
-----------------------
Overview
- PCB distributes power/signals to two Arduino boards, six rover motors (via external drivers), four servos, LiDAR, sensors, and a Raspberry Pi 5 V rail.
- All components are through-hole for hand assembly and field repair; board area grows but process stays low-risk.

Design goals/constraints
- Goals: easy soldering, robust servo/Pi power delivery, low-noise grounds, modular headers.
- Constraints: THT-only build, reliance on off-the-shelf modules limits miniaturization but speeds bring-up.

System architecture
- Two Arduino Nanos: first handles six motor drivers + encoders, second controls four MG996R servos (broom, flag, auxiliary).
- Three 5 A buck regulators: (1) servo rail, (2) LiDAR + second Arduino, (3) Raspberry Pi.

Power + decoupling strategy
- Bulk cap near source: 2200 µF to absorb low-frequency ripple.
- Additional 220 µF + 0.1 µF per rail to tame transients and high-frequency noise; place close to loads (servos, Pi, sensor modules).
- Servo spikes can brown out logic; keep servo returns/twisted loops isolated from sensor/logic grounds when routing.

Stack-up and routing
- 4-layer: F.Cu signal (1 oz), In1.Cu GND (0.5 oz), In2.Cu GND (0.5 oz), B.Cu power (1 oz).
- Maintain solid GND planes for low-impedance return paths; avoid splits unless return current analysis is done.
- Track/via rules: signals 1.0 mm traces w/ 1.2/0.6 mm vias; power 2.0 mm traces w/ 1.6/0.8 mm vias. Use multiple vias in parallel for high-current transitions.

Protection + connectors
- Fuse present on main input for overcurrent protection.
- Reverse polarity protection footprint optional (removed due to XT30 orientation confidence); consider leaving pads/jumper to re-add later.
- Label headers with signal/voltage/ground and mark pin 1; pin headers break out servos, LiDAR, sensors, Pi power, etc.

Assembly / bring-up notes
- Run ERC/DRC before ordering. Verify connector footprints/orientation.
- Power-up sequence: current-limited bench supply → validate buck outputs no-load → add Arduino/sensors → add servos/Pi while monitoring droop.
- Check fuse rating, regulator temps, high-current traces during load testing.

Known issues + future improvements
- Schematic digital nets currently mislabeled (all "DIGI"); need unique names (DIGI1, DIGI2, ...).
- PMOS selection for ideal diode / reverse protection TBD; specify VDS, ID, RDS(on), thermal handling, gate protection when completing.
- Consider extra footprints: test points per rail, optional reverse polarity device, current-shunt footprints.

Rev A post-manufacture fix
- Found +18V rail short due to rotated polarized capacitors (pads tied to wrong nets). Resolved by rotating caps, correcting footprints, verifying routing, and fixing silkscreen polarity markings.

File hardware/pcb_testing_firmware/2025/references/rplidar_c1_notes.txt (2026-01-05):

RPLIDAR C1 Notes
-----------------
General
- 360° 2D LiDAR (C1M1-R2) with 0.05–12 m range (white target, 70% reflectivity) and ~0.72° angular resolution at 10 Hz scan rate (5000 samples/s).
- Uses TOF ranging, clockwise rotation at ~600 rpm; outputs distance+angle per sample plus reflectivity/start flag bits.
- Class 1 laser (905 nm, ~20 W peak pulses) with contactless power/signal transmission; rated for long-life continuous scanning.
Power + Electrical
- Requires single 5 V supply for scanner + motor (4.8–5.2 V recommended); startup current ~800 mA, steady ~230–260 mA @10 Hz.
- Supply ripple should be <150 mV to avoid noise and radiation issues; keep leads short and add local bulk capacitance if sharing a rail.
- Interface connector: XH2.54-5P (Red=VCC, Yellow=TX out, Green=RX in, Black=GND). Motor speed is controlled via protocol commands (no separate motor supply).
Communication
- Serial interface: 3.3 V TTL UART at 460800 bps, 8N1.
- Output logic high ≈3.3 V, so logic-level translation needed if MCU inputs are not 3.3 V tolerant. Arduino Nano Every inputs tolerate up to 5 V, so direct connect is OK; but Arduino TX must not exceed 3.3 V when driving lidar RX (use level shifting or voltage divider).
- Protocol compatible with prior RPLIDAR A/S series; SDK available on GitHub (https://github.com/Slamtec/rplidar_sdk).
Mechanical / Integration
- Weight ~110 g; operating -10°C to 40°C.
- Provide clear optical window; avoid blocking scan path.
- Mount using M2.5 screws ≤4 mm depth.
Testing on Arduino Every
- Possible to test LiDAR communication using Arduino Every via UART (Serial1/SoftwareSerial) provided: (1) 5 V supply capable of ≥1 A surge, (2) 3.3 V-compatible TX toward LiDAR (use resistor divider or MOSFET level shifter), (3) firmware implementing the Slamtec protocol or using available Arduino-friendly drivers.
- For final rover integration, LiDAR data should be streamed to Raspberry Pi 5 for higher-level processing; Arduino-only tests should focus on verifying power rail stability and UART link quality.

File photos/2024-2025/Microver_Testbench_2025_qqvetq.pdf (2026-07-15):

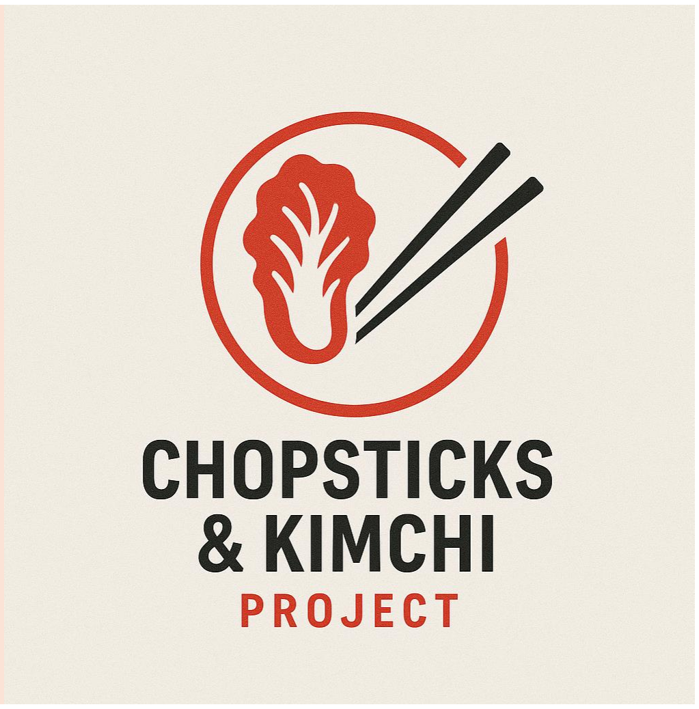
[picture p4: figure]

# Chopsticks & Kimchi Project

Steven B., Laura G., Lucas L., Tim W.

# Table of contents

# Timeline

# Mechanical

# Electrical

# Software

# Other

steven.bang@stu.rosey.ch, laura.guo@stu.rosey.ch, haolin.liu@stu.rosey.ch, tianran.wang@stu.rosey.ch

# Timeline

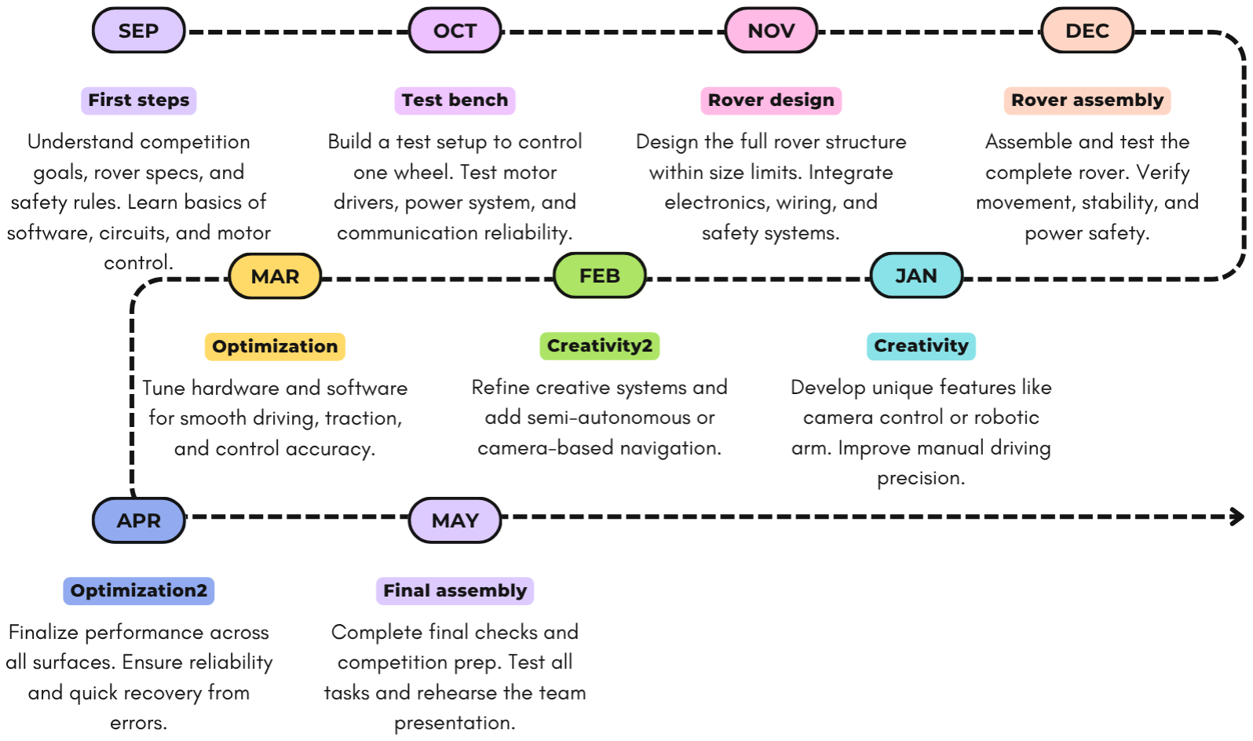
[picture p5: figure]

# Mechanical

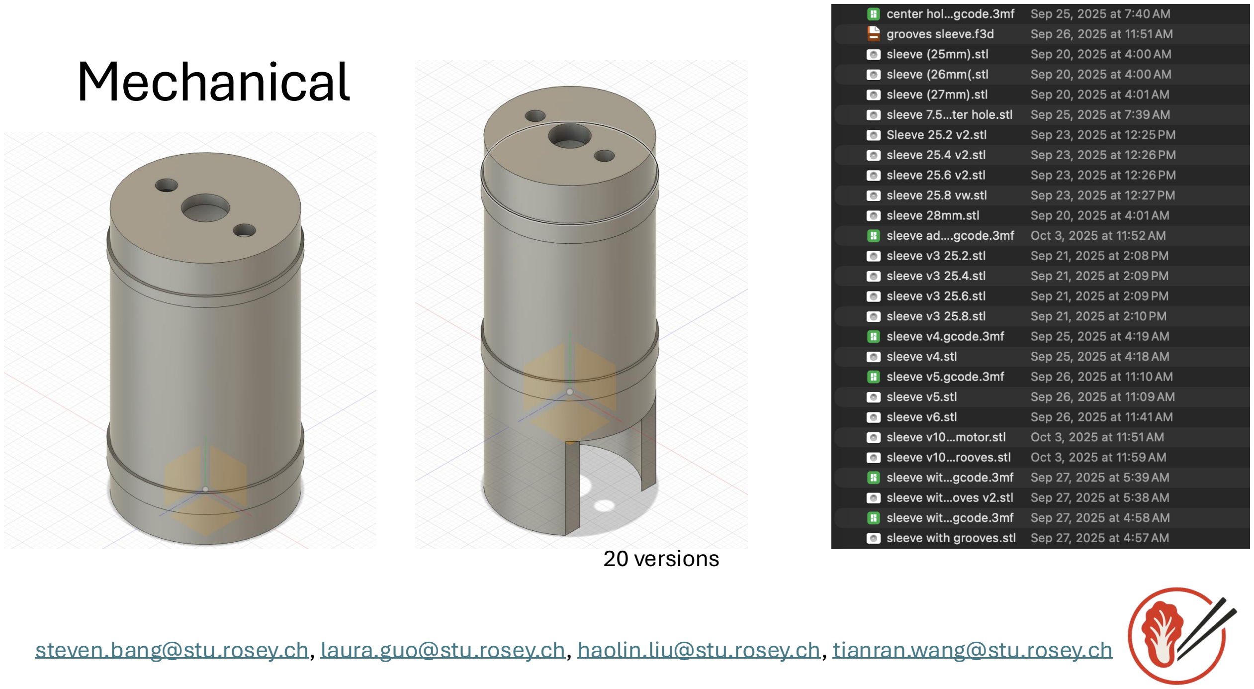
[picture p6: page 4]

# 20 versions

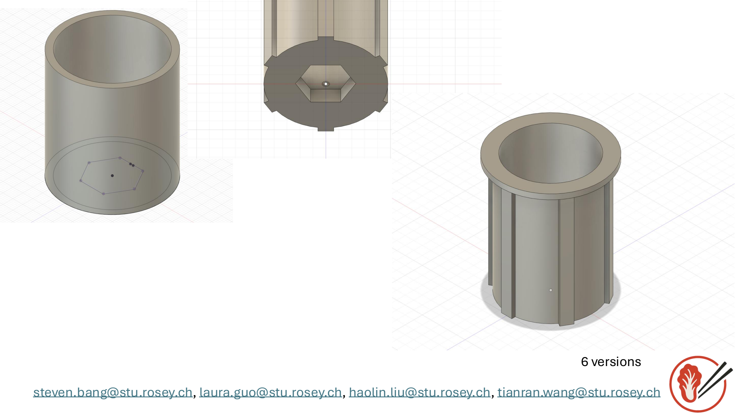
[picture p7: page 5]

# 6 versions

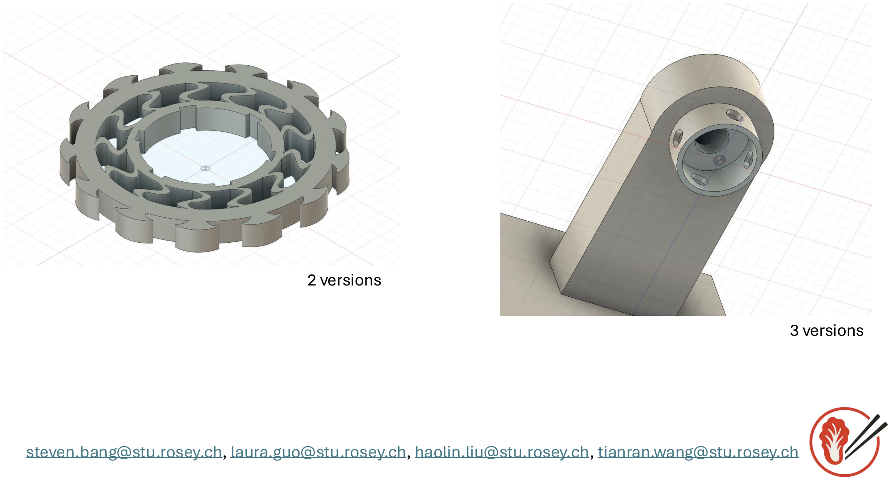
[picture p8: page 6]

# 2 versions

# 3 versions

# Electrical

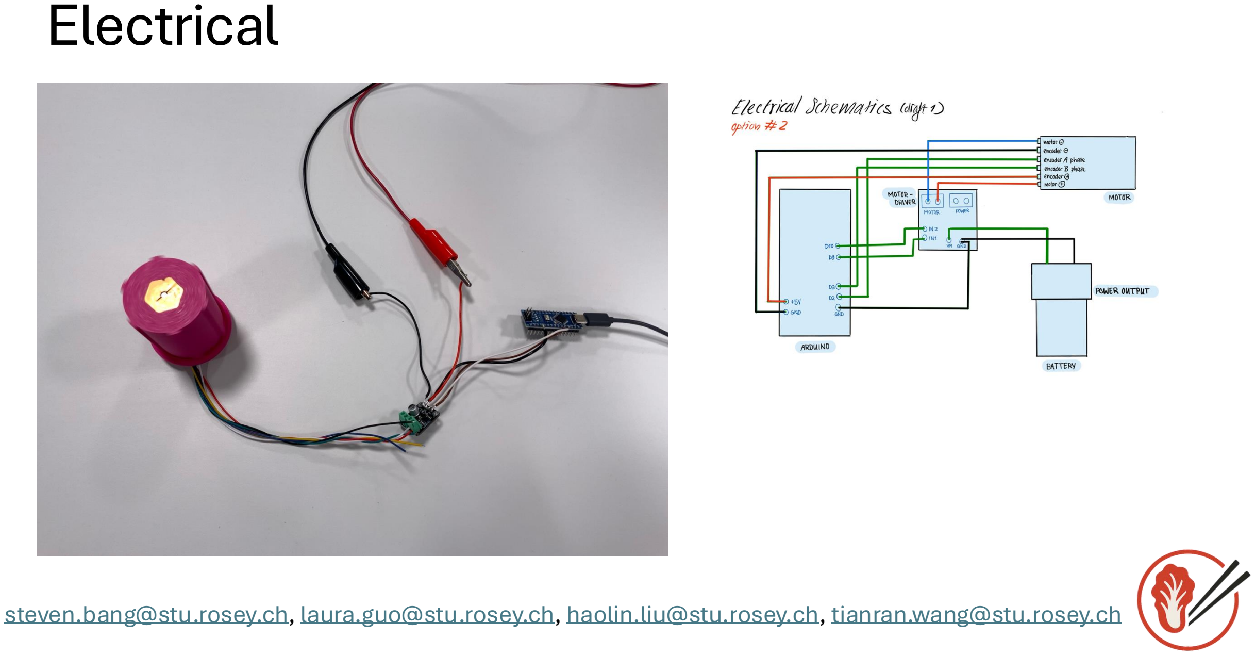
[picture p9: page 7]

# Software

# - Enterprise network limitations

# - Headless connection between laptop to Raspberry PI - Enterprise network connection in Raspberry PI

# - Communication between Raspberry PI and Arduino - Bluetooth connection with Controller - Handling controller raw input - Custom serial communication protocol - Arduino pin alignment - Raspberry PI missing software in Ubuntu 24.04.3 LTS

# In the foreseeable future - Remote PI camera connection (limited by enterprise network) - Controller input, buttons, and sensibility adjustment - ROS2 refactoring

# - Peripheral host: actuator, sensor, interface, and utility nodes oConnection between each nodes: possibly limited by network oPossibly using `joy` for controller - Possibly using `raspicam_node` for remote camera - Heard about `rviz2` for visualization, possibly need more sensors

# Software

# Management

Task Name | Progress | Assigned To | Created By | Created Date | Due date | Completed Date | Completed By
Mechanical - holding structure | Completed | BANG Steven | WANG Tianran | 10/03/2025 | 10/10/2025 | 10/13/2025 | BANG Steven
Electrical - Finish electronics connection with encoder pins | Not started | GUO Laura | WANG Tianran | 10/10/2025 | 11/07/2025
Mechanical - Finish sketch and fix size of sleeve | Completed | BANG Steven | WANG Tianran | 09/19/2025 | 09/26/2025 | 09/26/2025 | WANG Tianran
try out Pi camera | Completed | LIU Hao lin | WANG Tianran | 09/26/2025 | | 10/12/2025 | WANG Tianran
Electrical - Started a sketch of the test bench design | Completed | GUO Laura | WANG Tianran | 09/19/2025 | | 09/19/2025 | WANG Tianran
Electrical - Connect components according to schematic + start learning C++ | Completed | GUO Laura | WANG Tianran | 09/19/2025 | 09/26/2025 | 10/03/2025 | WANG Tianran
Software - self directed | Completed | LIU Hao lin | WANG Tianran | 09/19/2025 | 09/26/2025 | 09/19/2025 | WANG Tianran
Software - connect Pi to controller via bluetooth + bidirectional communication | Completed | LIU Hao lin | WANG Tianran | 09/23/2025 | 10/10/2025 | 10/10/2025 | WANG Tianran
Mechanical - complete cad of hub | Completed | BANG Steven | WANG Tianran | 09/26/2025 | 10/03/2025 | 10/04/2025 | BANG Steven
For software engineering to test - Test bench Arduino with code | Completed | WANG Tianran | WANG Tianran | 09/26/2025 | 09/26/2025 | 09/26/2025 | WANG Tianran
Mechanical - Started a sketch of the test bench design + Learn parts | Completed | BANG Steven | WANG Tianran | 09/19/2025 | 09/19/2025 | 09/20/2025 | BANG Steven
Electrical - Finish code for test bench | Completed | GUO Laura | WANG Tianran | 09/26/2025 | 10/03/2025 | 10/03/2025 | WANG Tianran
Name and Logo | Completed | BANG Steven;GUO Laura;WANG Tianran;LIU Hao lin | CAREBIA Iulius | 09/19/2025 | 09/26/2025 | 10/03/2025 | WANG Tianran
Finish Testbench Presentation | Not started | BANG Steven;GUO Laura;WANG Tianran;LIU Hao lin | WANG Tianran | 10/13/2025 | 10/31/2025

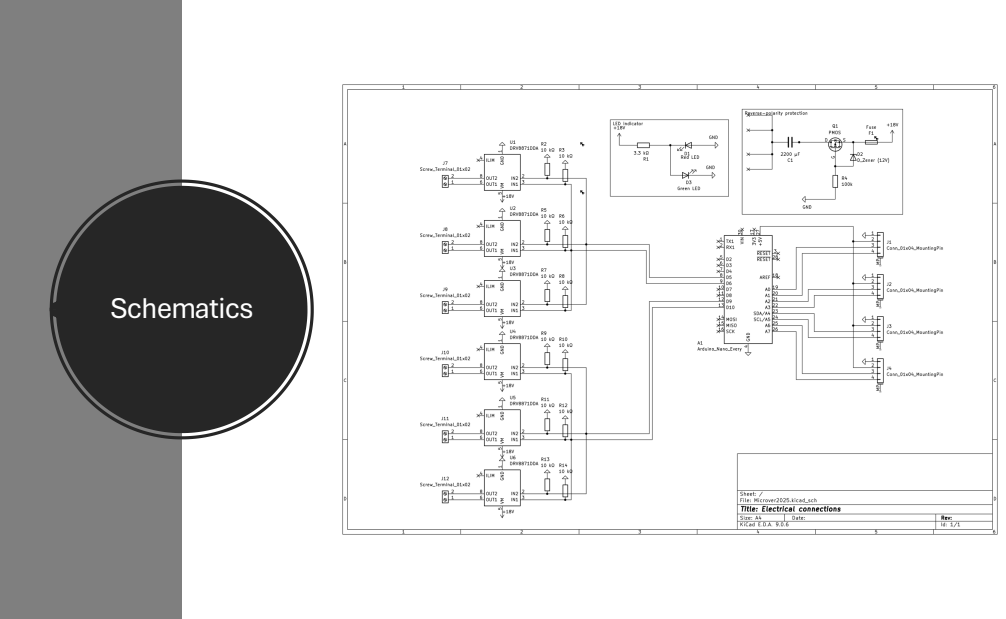
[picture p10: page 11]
Schematics

# Pull-down resistor

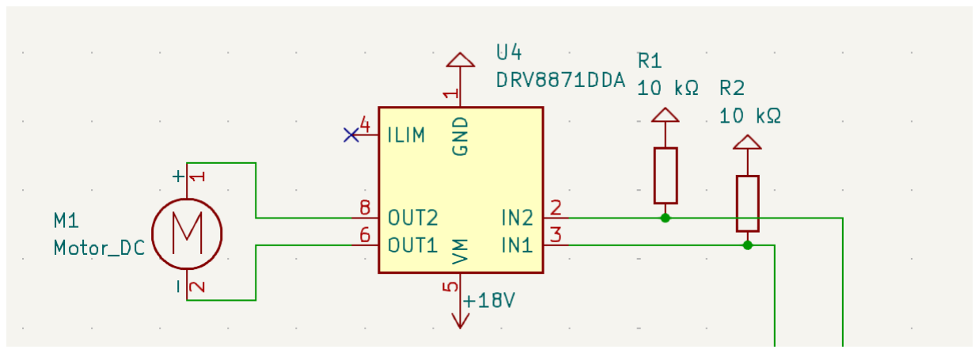
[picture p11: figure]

# Reverse-polarity

protection.

# - MOSFET opens when voltage difference is <-4

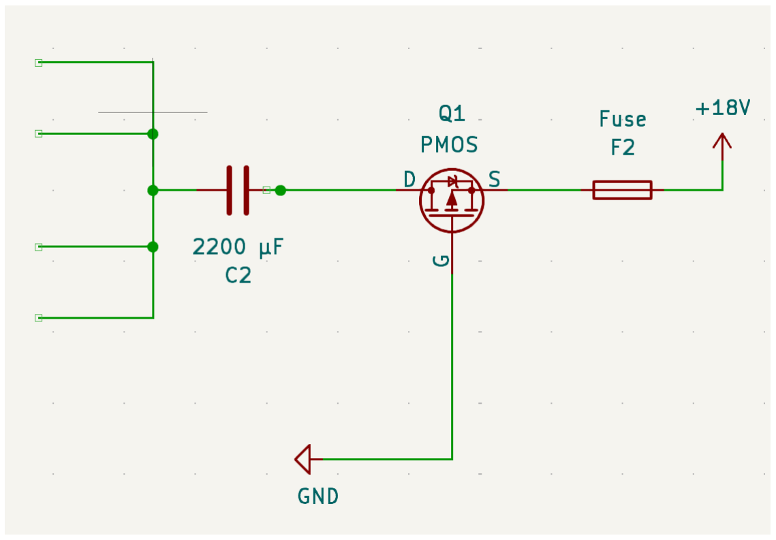
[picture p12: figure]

# Zenor diode

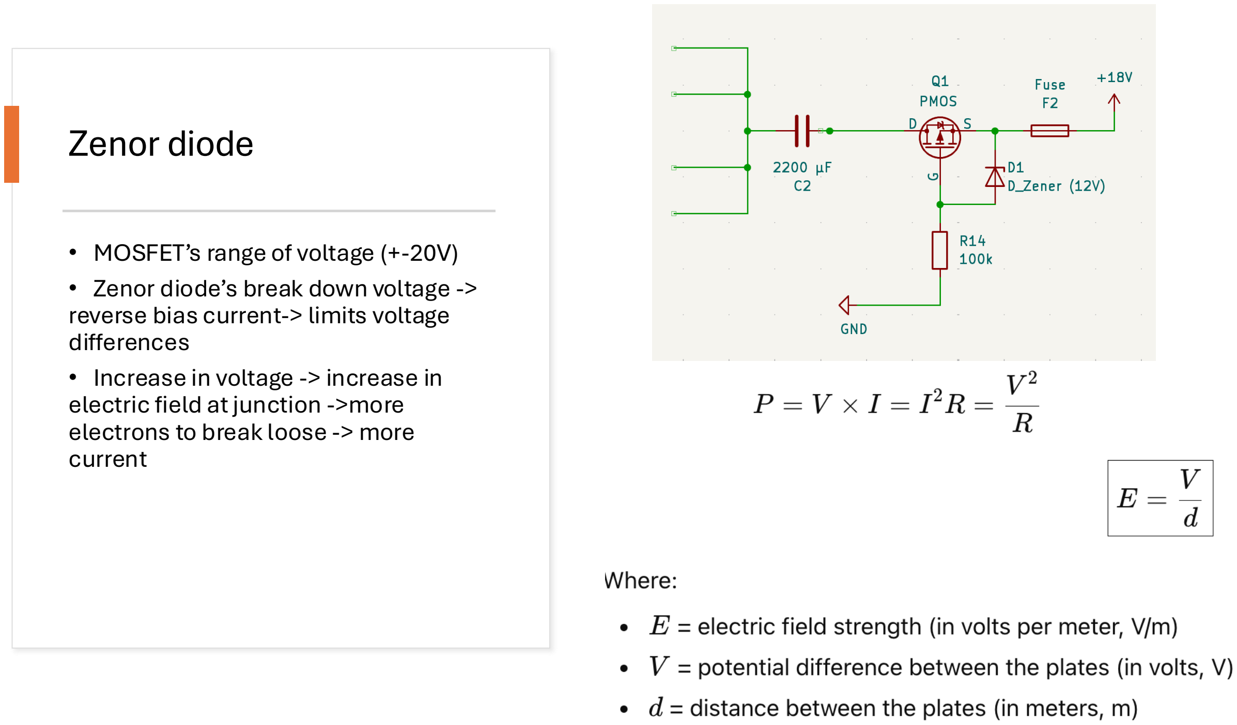
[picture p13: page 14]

# - MOSFET’s range of voltage (+-20V) - Zenor diode’s break down voltage -> reverse bias current-> limits voltage differences - Increase in voltage -> increase in electric field at junction ->more electrons to break loose -> more current


# LED indication

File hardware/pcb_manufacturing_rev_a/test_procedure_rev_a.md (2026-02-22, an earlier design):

# Arduino Rover Main PCB — Rev A
Bring-up & Functional Test Guide (using existing firmware sketches)

## 0) Equipment
- Bench supply, 18–25 V, current limit 1–5 A (XT30 input).
- DMM; optional oscilloscope for ripple.
- Loads: a few servos, the six DC motor driver harnesses, Raspberry Pi (optional later), and a small 5 V load (e.g., USB tester or 5 Ω/10 W resistor).
- USB cables for two Arduino Nano Every boards.
- Firmware sketches from `firmware/2025/`:
  - Drive/encoders/link: `firmware/2025/controllers/arduino_every1_test.ino`
  - Servos/link: `firmware/2025/controllers/arduino_every2_test.ino`
  - Quick isolates: drivetrain tests in `firmware/2025/diagnostics/drivetrain/`, link tests in `firmware/2025/diagnostics/link/`, servo tests in `firmware/2025/diagnostics/servos/`.

## 1) Visual / Continuity (unpowered)
1. Inspect XT30 polarity, buck regulator orientation, electrolytic capacitor polarity, header silks for servos/LiDAR/Pi.
2. DMM continuity:
   - Main VIN to GND: open.
   - Each 5 V rail to GND: open.
   - Check fuse continuity.

## 2) Rail Bring-Up (no loads)
1. Set supply 18 V, limit 0.5 A. Leave Arduinos, servos, Pi disconnected.
2. Power ON. Measure the three 5 V rails (servo, LiDAR/Every2, Pi). Expected 4.9–5.1 V, no appreciable ripple.
3. If OK, raise current limit to 2 A and retest rails.

## 3) Add Arduinos Only
1. Plug in both Nano Every boards; keep motor drivers/servos disconnected.
2. Power the main board from bench supply (still ~18–20 V, limit 2 A).
3. Verify 5 V rails stay within spec; boards enumerate over USB.

## 4) Servo Rail Check
1. Connect one servo to Servo1 header.
2. Upload `servo1_test.ino` (Every 2). Run for 1–2 minutes; watch rail droop and noise. Repeat for other channels as needed.
3. If stable, connect up to four servos and run `arduino_every2_test.ino` to sweep sequentially. Monitor total supply current and any brownout of logic rails.

## 5) Motor/Encoder Side
1. Connect motor driver harnesses and encoders to Every 1 side.
2. Upload `left_side_test.ino` and `right_side_test.ino` individually to verify each side drives and encoders count.
3. Then load `arduino_every1_test.ino` to exercise both sides with ramp/brake and capture encoder snapshots. Expect encoder counts to rise when wheels spin and link pings to Every 2 if connected.

## 6) Inter-Arduino Link
1. With both sketches (`arduino_every1_test.ino` on Every 1, `arduino_every2_test.ino` on Every 2), verify periodic `PING/ACK` at 38 400 baud over D11/D12.
2. Check that Every 1 reports servo ID and active flag in the ACK summary; no link timeouts should accumulate.

## 7) Full Stack (optional Pi)
1. Connect Raspberry Pi to the Pi 5 V rail; keep servos connected.
2. Power from bench supply at 20–22 V, limit 5 A. Confirm Pi boots and rails hold >4.9 V under servo sweeps and motor ramps at low duty.

## 8) Fault/Protection Checks
1. Brownout simulation: temporarily add a 1–2 Ω load to the servo rail during a sweep; confirm Arduinos stay powered and no resets occur.
2. Fuse/overcurrent sanity: briefly exceed normal load (e.g., stall one motor at low PWM) while watching supply current. Stop if the fuse runs hot or rails sag hard.

## 9) Pass/Fail Notes
- All three 5 V rails within 4.9–5.1 V no-load and under typical servo/motor test loads.
- No Arduino resets during servo sweeps or motor ramps.
- Encoders count correctly; link PING/ACK shows no errors.
- No excessive heating on bucks or headers during 5–10 minute mixed actuator exercise.

## If Issues Arise
- Rail droop/noise: add temporary bulk on the affected rail; check connector seating.
- Link errors: re-seat D11/D12 wires; confirm baud at 38 400.
- Encoder miscounts: verify A/B wiring and pull-ups; swap A/B if counts decrease in forward.

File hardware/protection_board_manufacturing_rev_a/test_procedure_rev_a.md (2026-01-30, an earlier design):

# Power Protection Board — Rev A
## Bench Test & Validation Procedure (Step-by-Step)

### 0) Equipment & Setup
- Bench supply with CC limit (0–30 V, ≥5 A), sense leads if available.
- DMM (voltage + continuity); optional oscilloscope for ramp/PGD timing.
- Known load: start with 1–2 Ω / 50 W resistor (or electronic load), later real system load.
- Shorting tool: momentary-rated jumper or toggle to briefly short VOUT to GND.
- Logic pull-up for PGD: 3.3 V or 5 V through 10–47 kΩ; logic reference ground common with board.
- Cables: keep VIN leads short; use same gauge for GND and VIN.

### 1) Visual & Continuity Checks (unpowered)
1. Inspect for solder bridges, rotated parts (pay attention to SOT-23 orientation, TVS polarity, electrolytic caps polarity).
2. Verify pass FET pads wetted and no debris between pins.
3. Continuity with DMM (beeper):
   - VIN+ to VIN- (GND): open (>100 kΩ).
   - VOUT+ to VOUT- (GND): open.
   - VIN+ to VOUT+: ~>100 kΩ (through MOSFET body diode, may read mega-ohms forward-blocking).
   - PGD pad to GND: open.

### 2) Initial Power-On (no load) — 6S validation first
1. Bench supply to VIN, current limit = 0.5 A, set VIN = 22.2 V (6S nominal). Do **not** connect load.
2. Enable supply. Expected:
   - Inrush dv/dt ramp; VOUT rises smoothly to VIN (small delay from LM5069 soft-start).
   - Supply current: a few mA after ramp.
   - PGD: LOW during ramp, then HIGH when VOUT within window (use pull-up and DMM/scope).
3. If current hits limit or VOUT stalls, power off and inspect.

### 3) Reverse Polarity Check
1. Turn supply off. Swap leads (VIN– to +, VIN+ to –). Set current limit 0.5 A, VIN = 12 V.
2. Enable. Expected: almost zero current (< a few mA), VOUT ≈ 0 V, PGD LOW. Turn off immediately if current spikes.
3. Restore correct polarity before continuing.

### 4) PGD Timing & dv/dt Ramp
1. Correct polarity; VIN = 20 V, current limit 2 A.
2. Scope channels: CH1 on VOUT, CH2 on PGD (with pull-up). Trigger on VIN enable.
3. Enable supply. Measure:
   - VOUT rise time (controlled by dv/dt cap ~150 nF). Expect smooth ramp (tens of ms range, no overshoot).
   - PGD goes HIGH after VOUT is stable; note delay vs VOUT reaching ~90–95% VIN.
4. Record rise time and PGD delay for log.

### 5) Load Test — Normal Operation
1. Connect resistive load that draws ~2–3 A at 20 V (e.g., 7–10 Ω / 50 W). Current limit 5 A.
2. Power on. Expected: VOUT ≈ VIN with minimal droop, PGD HIGH, supply current ≈ load current.
3. Monitor MOSFET temperature (touch/IR) — should be warm at most for short test.
4. Step VIN from 18 V → 22 V → 25 V while watching PGD stays HIGH and no audible chatter.

### 6) Current Limit / Short-Circuit Behavior
1. Remove resistive load. Current limit 5–8 A.
2. Power on at 20 V, wait for PGD HIGH.
3. Briefly short VOUT to GND (≤0.5 s) with momentary jumper.
   - Expected: LM5069 enforces current limit then times out (~320 ms) and latches OFF; PGD goes LOW.
   - Supply current should not exceed limit; no damage or excessive heating.
4. Clear short, power-cycle VIN (or toggle EN if available) to recover. Confirm PGD returns HIGH and VOUT normal.

### 7) UVLO/OVLO Window Check (Rev A as-built, then optional 5S retune)
1. No load. Start VIN at 18 V (lower bound for 6S), limit 0.5 A.
2. Increase VIN slowly and note PGD transition LOW→HIGH (UVLO upper threshold). Record value.
3. Continue raising VIN and note PGD HIGH→LOW (OVLO) if present; for 6S expect window near 22–25 V depending on stuffing.
4. Decrease VIN and capture hysteresis points (PGD drops slightly below the rising thresholds).
5. **If 6S results pass and you want 5S operation:** power down, replace R3→2 kΩ, R5→24 kΩ, R7→3 kΩ (Rev B values), then repeat Steps 2–7 with VIN sweep 14–23 V; expect UVLO ~15–16 V and OVLO ~22–23 V for 5S.

### 8) Hot-Plug / Inrush Observation
1. Set supply to 20 V, limit 5 A, output OFF.
2. Connect board first, then hot-plug supply ON. Watch VOUT with scope for overshoot and current spike shape (should show controlled ramp, no large overshoot).
3. Repeat with 25 V, same limit. Abort if overshoot >1 V above VIN or audible clicks/arcs.

### 9) Long Dwell at Moderate Load
1. Attach 2–3 A load at 20–22 V.
2. Run for 10 minutes; monitor MOSFETs, sense resistor, TVS, and LM5069 temperature (finger/IR).
3. PGD should remain HIGH; VOUT droop minimal (<100–150 mV typical). No smell/discoloration.

### 10) Documentation & Sign-off
- Log all measured thresholds: UVLO/OVLO up/down, ramp time, PGD delay, current-limit response.
- Record ambient temperature and load used.
- Note any anomalies (PGD chatter, audible buzz, overheating). If present, recheck sense resistor value, dv/dt capacitor, and gate resistors.

### Pass/Fail Criteria (quick checklist)
- Reverse protection blocks current; no heat or damage.
- Controlled VOUT ramp; PGD behaves: LOW during ramp/fault, HIGH when stable.
- Carries 3 A continuous for short dwell without excessive heating.
- Current limit engages and recovers after short; no latch-up/damage.
- UVLO/OVLO thresholds within expected band for Rev A resistor values.

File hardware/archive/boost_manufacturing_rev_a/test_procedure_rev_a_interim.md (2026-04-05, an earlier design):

# Boost Converter - Rev A Interim

Short bench check for Rev A after removing C1 and replacing C2/C7 with 50 V parts. Use this only for the interim Rev A build.

## Equipment
- Bench supply, 0-30 V, with current limit
- DMM and scope
- Load for 36 V, about 1-5 A

## Quick Test
1. Prep: C1 should be removed and C2/C7 should be 50 V parts. Inspect the board and confirm there is no short on VIN, VOUT, or VIN-to-VOUT.
2. Start with no load at 18 V / 0.5 A. VOUT should rise to about 36 V with no big overshoot.
3. At 20 V, capture startup on the scope. The ramp should be clean and controlled.
4. Load test at about 1 A, then about 5 A. Output should stay within about +/-2%, with no audible instability or fast heating.
5. Sweep VIN through 18 V, 22 V, and 25 V while holding a moderate load. Regulation should stay stable.
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

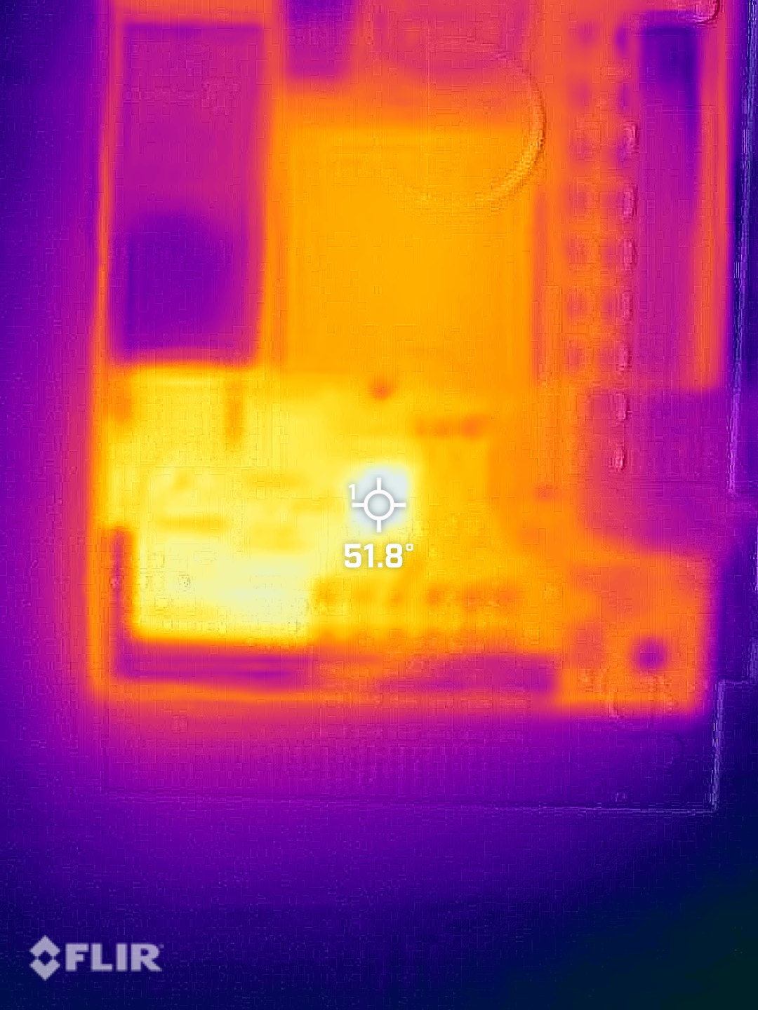
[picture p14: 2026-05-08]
hardware/final/buck_manufacturing_rev_c/Test results/Thermal/5A/After 30mins.JPG

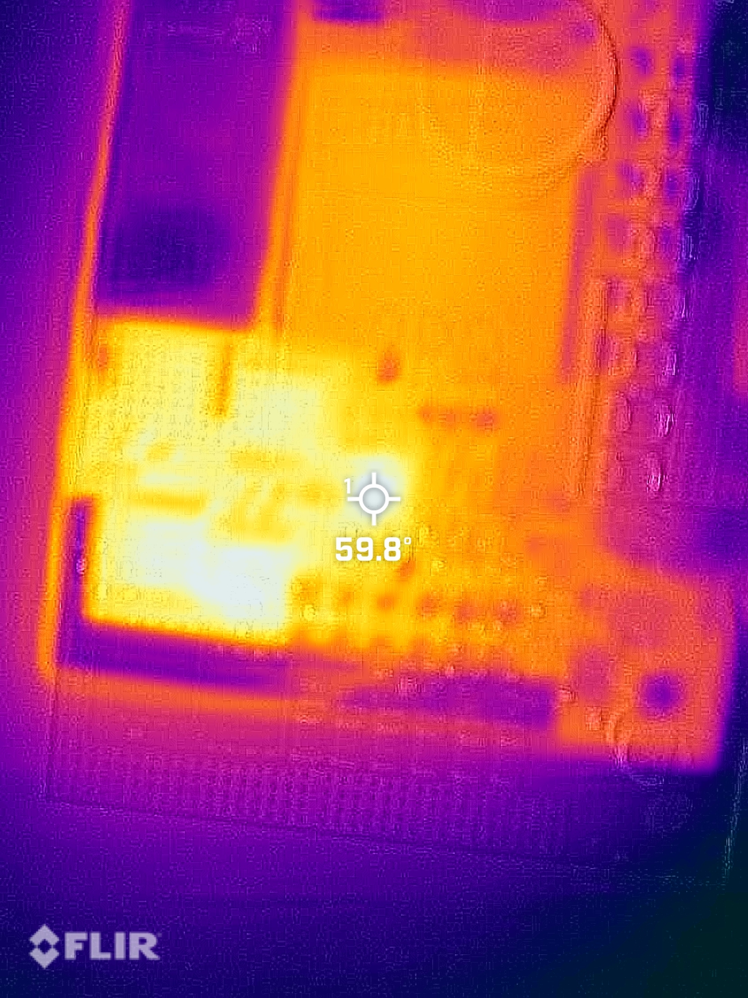
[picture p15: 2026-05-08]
hardware/final/buck_manufacturing_rev_c/Test results/Thermal/12.5A/After 30mins.JPG

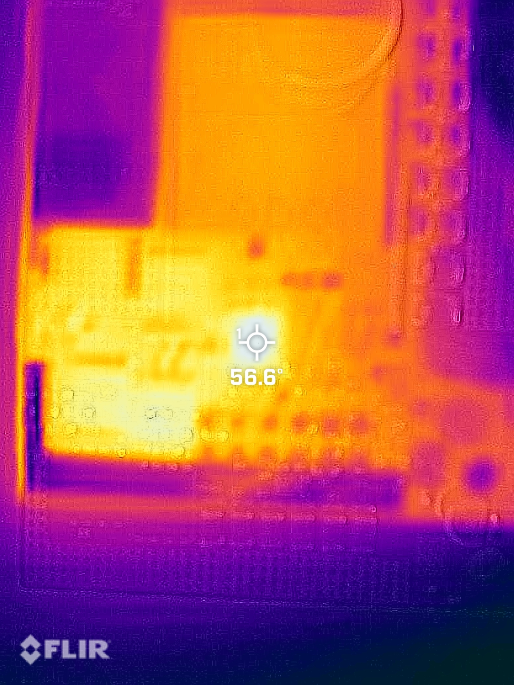
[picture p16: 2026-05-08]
hardware/final/buck_manufacturing_rev_c/Test results/Thermal/7.5A/After 20mins.JPG

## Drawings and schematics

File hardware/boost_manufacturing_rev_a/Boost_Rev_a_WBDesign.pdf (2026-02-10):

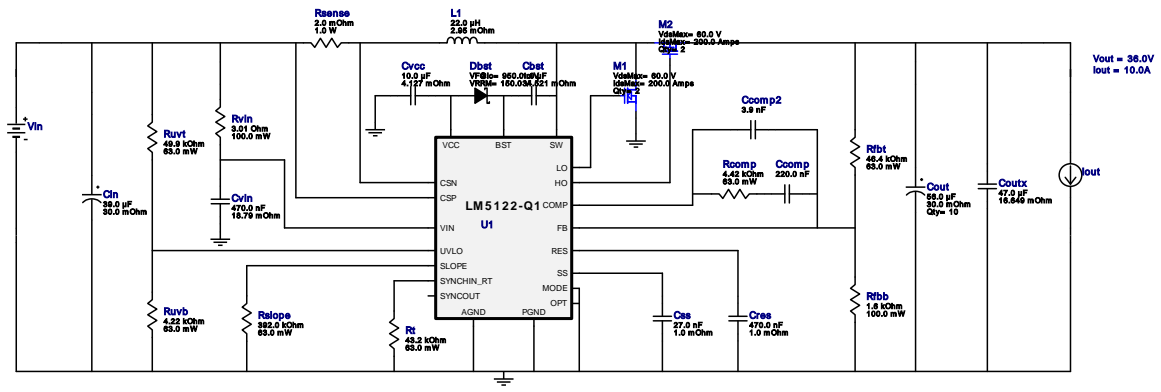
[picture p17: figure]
L1 22.0 µH 2.95 m Ohm; Rfbt 46.4 kOhm; Ruvt 49.9 kOhm; Cout 56.0 µF; 30.0 m Ohm Qty= 10; Rsense 2.0 m Ohm 1.0 W; SYNCOUT; OPT; CSN; CSP; VIN; UVLO; SYNCHIN_RT; AGND; COMP; SLOPE; MODE; RES; PGND; VCC; BST; Ccom p 220.0 nF; VdsMax= 60.0; IdsMax= 200.0; Am ps Qty= 2; Cin 39.0 µF 30.0 m Ohm; Vout = 36.0V Iout = 10.0A Cvcc 10.0 µF 4.127 m Ohm; Css 27.0 nF 1.0 m Ohm; Rslope 392.0 kOhm 63.0 m W; Dbst VF@Io= 950.0 m V; VRRM= 150.0 V; Rcom p 4.42 kOhm 63.0 m W; Ruvb 4.22 kOhm 63.0 m W; Ccom p2 3.9 nF; Cbst 1.0 µF; 34.521 m Ohm; Rvin 3.01 Ohm 100.0 m W; Coutx 47.0 µF 16.649 m Ohm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

Copyright © 2026, Texas Instruments Incorporated | 1 | ti.com/webench

WEBENCH®
Design Report LM5122QMH/NOPB : LM5122QMH/NOPB 18V-24V to 36.00V @ 10A January 17, 2026 14:24:49 GMT-06:00

## WEBENCH ® Design Report

Design : 5 LM5122QMH/NOPB
LM5122QMH/NOPB 18V-24V to 36.00V @ 10A

VinMin = 18.0V
VinMax = 24.0V
Vout = 36.0V
Iout = 10.0A

Device = LM5122QMH/NOPB
Topology = Boost
Created = 2026-01-17 05:07:51.755 BOM Cost = $29.93
BOM Count = 35
Total Pd = 9.22W
1. This regulator device is qualified for Automotive applications. All passives and other components selected in this design may not be qualified for Automotive applications. The user is required to verify that all components in the design meet the qualification and safety requirements for their specific application.View WEBENCH(R) Disclaimer.

### Design Alerts

Component Selection Information
The LM5122-Q1 is qualified for Automotive applications. All passives and other components selected in this design may not be qualified for Automotive applications. The user is required to verify that all components in the design meet the qualification and safety requirements for their specific application.

## Electrical BOM

Name | Manufacturer | Part Number | Properties | Qty Price | Footprint
Cbst | Taiyo Yuden | MSASU21GSB7105KTNA01 (https://ds.yuden.co.jp/TYCOMPAS/ut/detail?pn%3DMSASU21GSB7105KTNA01%26u%3DM) Series= X7R | Cap= 1.0 uF ESR= 34.521 mOhm VDC= 50.0 V IRMS= 1.26652 A
1 | $0.04
| | | | | 0805 7 mm²
Ccomp | Kemet | C1210C224J3GACTU (http://www.kemet.com/docfinder?Partnumber%3DC1210C224J3GACTU) Series= C0G/NP0

Cap= 220.0 nF
VDC= 5.0 V
IRMS= 0.0 A

1 $1.63
1210 15 mm²
Ccomp2 | TDK | CGA4C2C0G1H392J060AA (http://product.tdk.com/capacitor/mlcc/en/documents/mlcc%5Fautomotive%5Fgeneral%5Fen.pdf) Series= C0G/NP0

Cap= 3.9 nF
VDC= 50.0 V
IRMS= 0.0 A

1 $0.04
0805 7 mm²
Cin | Panasonic | 35SVPF39M Series= SVPF

Cap= 39.0 uF
ESR= 30.0 mOhm
VDC= 35.0 V
IRMS= 2.8 A

1 $0.67

CAPSMT_62_E7 106 mm²
Cout | Panasonic | EEHZA1J560P Series= ZA

Cap= 56.0 uF
ESR= 30.0 mOhm
VDC= 63.0 V
IRMS= 1.8 A

10 $0.93
Panasonic_G 151 mm²
Coutx | TDK | CKG57NX7R1H476M500JH (https://product.tdk.com/ja/search/capacitor/ceramic/mlcc/info?part%5Fno%3DCKG57NX7R1H476M500JH) Series= X7R

Cap= 47.0 uF
ESR= 16.649 mOhm
VDC= 50.0 V
IRMS= 0.0 A

1 $5.07

2220 54 mm²

Cres | Taiyo Yuden | TMK212BJ474KD-T (http://www.yuden.co.jp/ut/product/pdf/djmk%5Fe.pdf) Series= X5R

Cap= 470.0 nF
ESR= 1.0 mOhm
VDC= 20.0 V
IRMS= 0.0 A

1 $0.02
0805 7 mm²

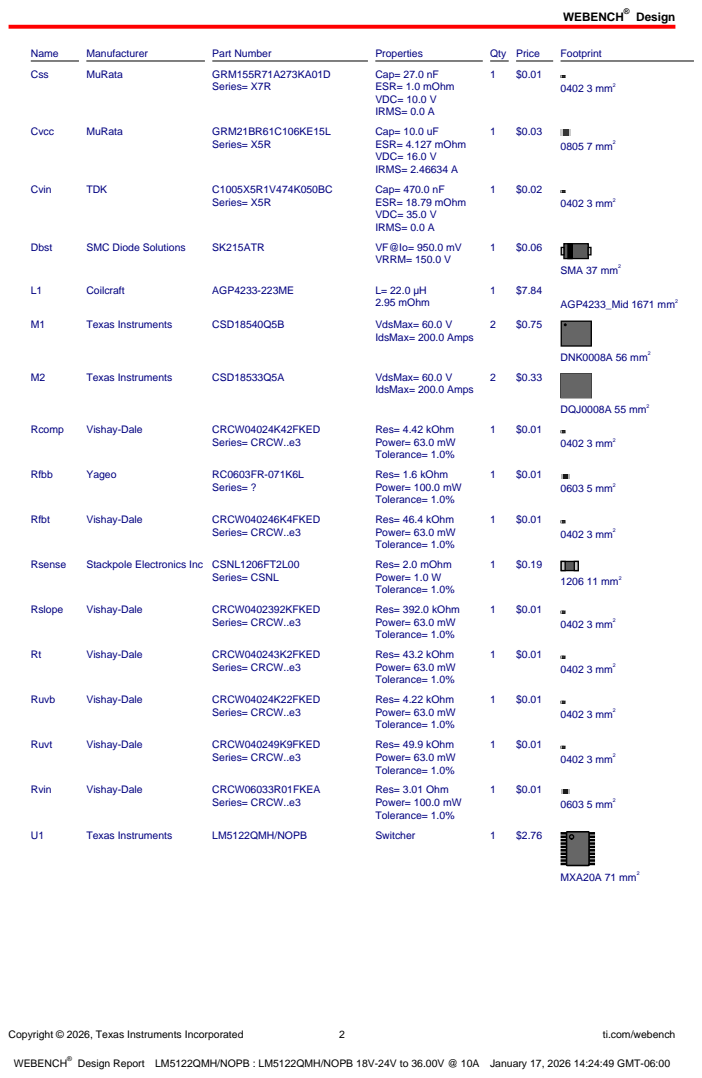
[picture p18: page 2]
Design; Copyright © 2026, Texas Instruments Incorporated; ti.com/webench; Name; Manufacturer; Part Number; Properties; Qty Price; Footprint; Css; MuRata; GRM155R71A273KA01D; Series= X7R; Cap= 27.0 nF ESR= 1.0 mOhm VDC= 10.0 V IRMS= 0.0 A; 0402 3 mm²; Cvcc; GRM21BR61C106KE15L; Series= X5R; Cap= 10.0 uF ESR= 4.127 mOhm VDC= 16.0 V IRMS= 2.46634 A; 0805 7 mm²; Cvin; TDK; Cap= 470.0 nF ESR= 18.79 mOhm VDC= 35.0 V IRMS= 0.0 A; Dbst; SMC Diode Solutions; SK215ATR; VRRM= 150.0 V; SMA 37 mm²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

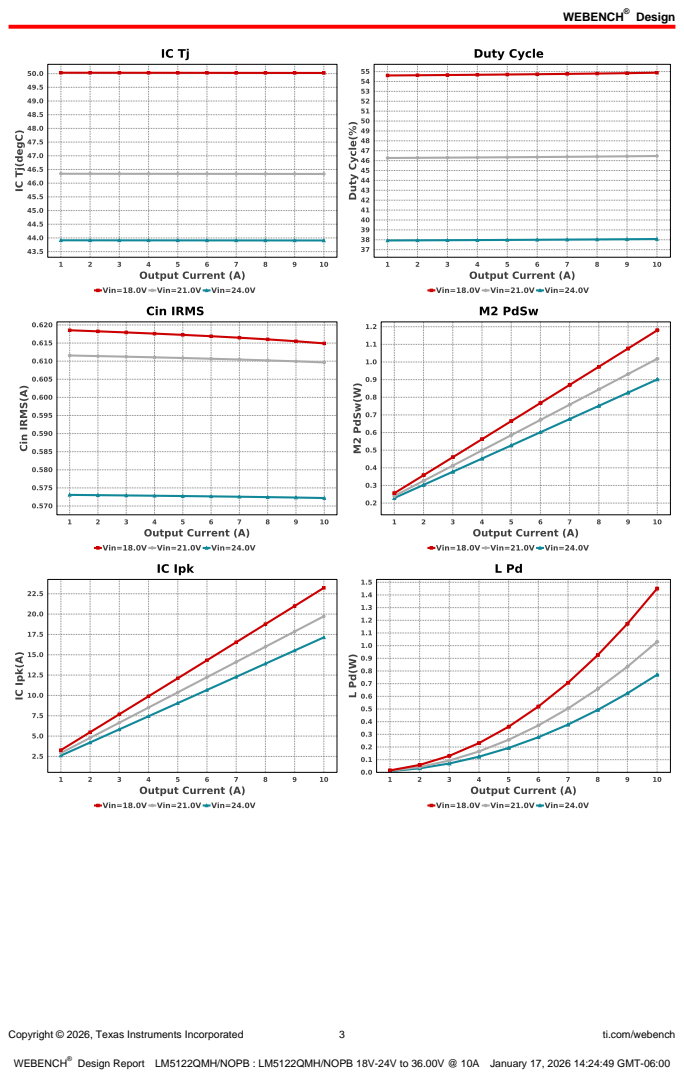
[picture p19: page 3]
Copyright © 2026, Texas Instruments Incorporated; ti.com/webench

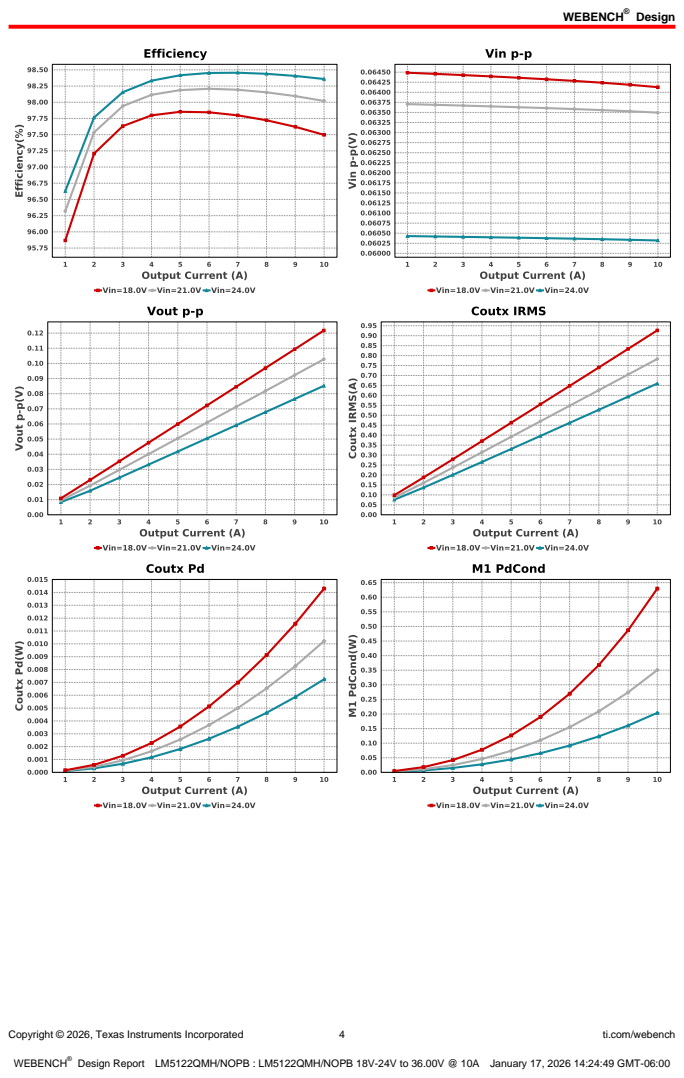
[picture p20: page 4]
Copyright © 2026, Texas Instruments Incorporated; ti.com/webench

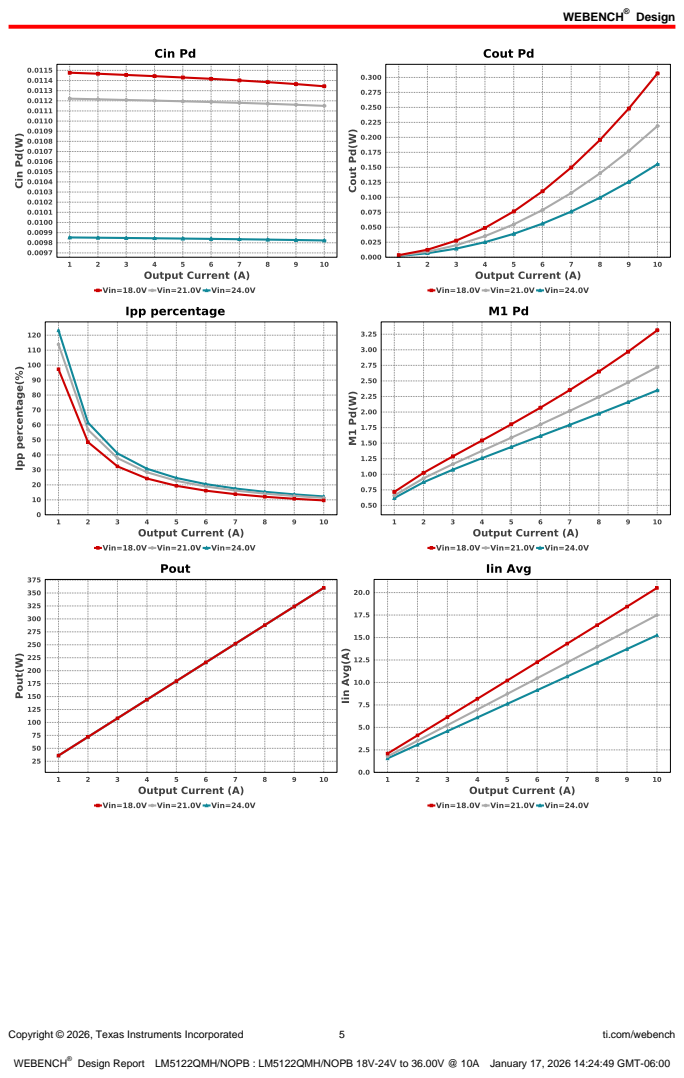
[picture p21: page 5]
Copyright © 2026, Texas Instruments Incorporated; ti.com/webench

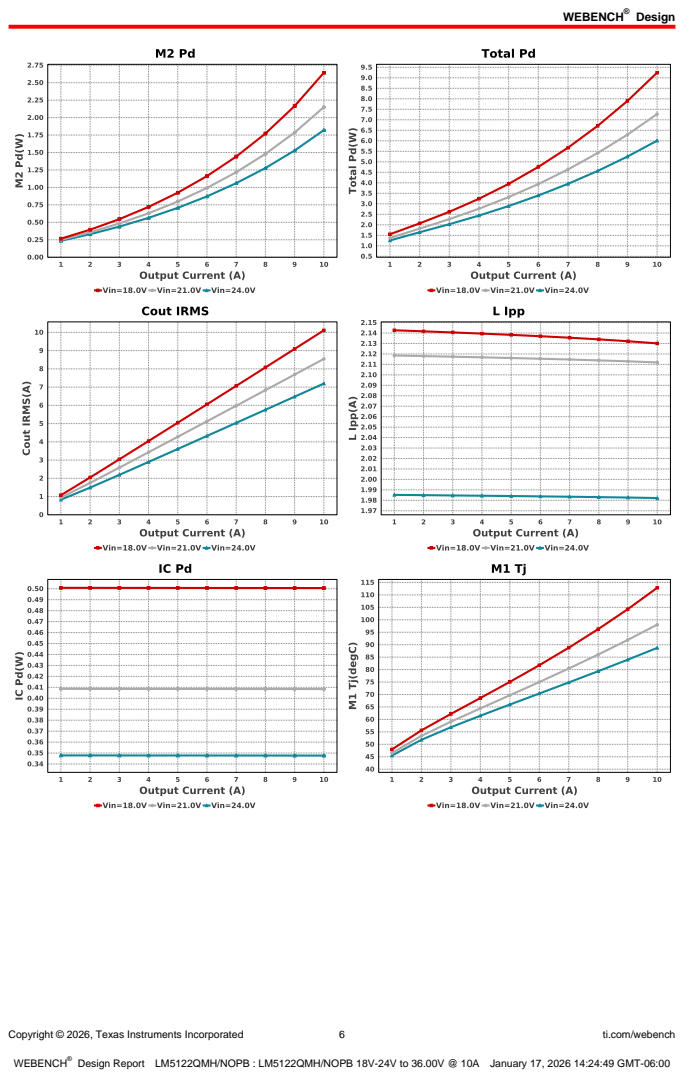
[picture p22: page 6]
Copyright © 2026, Texas Instruments Incorporated; ti.com/webench

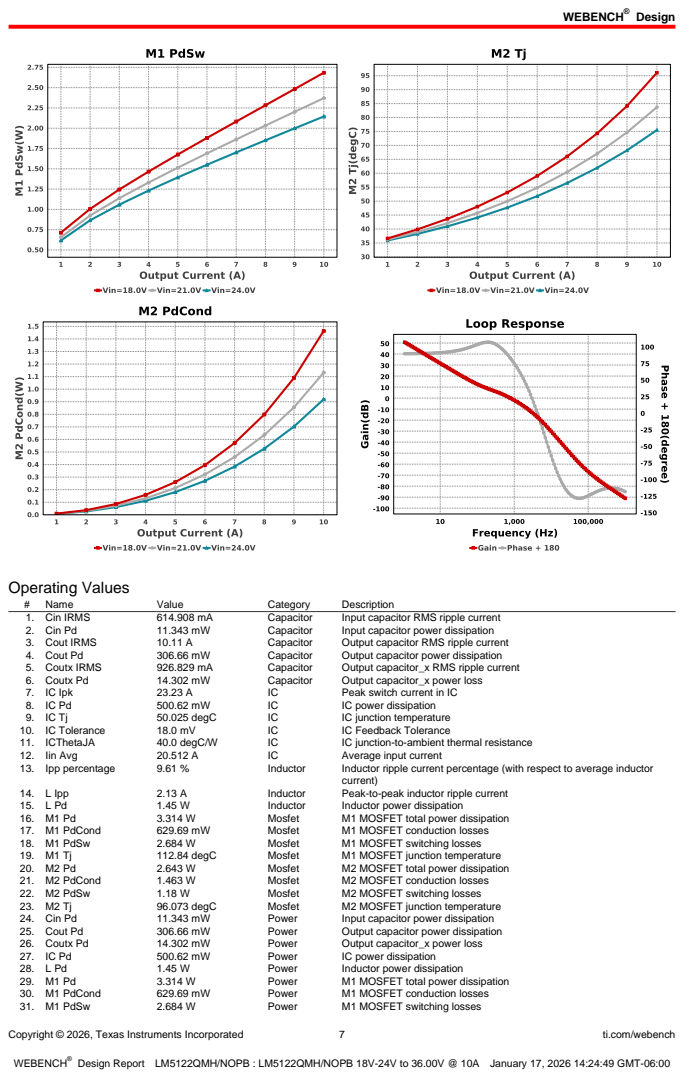
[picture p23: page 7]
Copyright © 2026, Texas Instruments Incorporated; ti.com/webench; Operating Values; Name; Value; Category; Description; 1. Cin IRMS; Capacitor; Input capacitor RMS ripple current; 2. Cin Pd; Input capacitor power dissipation; 3. Cout IRMS; Output capacitor RMS ripple current; 4. Cout Pd; Output capacitor power dissipation; 5. Coutx IRMS; Output capacitor_x RMS ripple current; 6. Coutx Pd; Output capacitor_x power loss; 7. IC Ipk; Peak switch current in IC; IC power dissipation; 50.025 degC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

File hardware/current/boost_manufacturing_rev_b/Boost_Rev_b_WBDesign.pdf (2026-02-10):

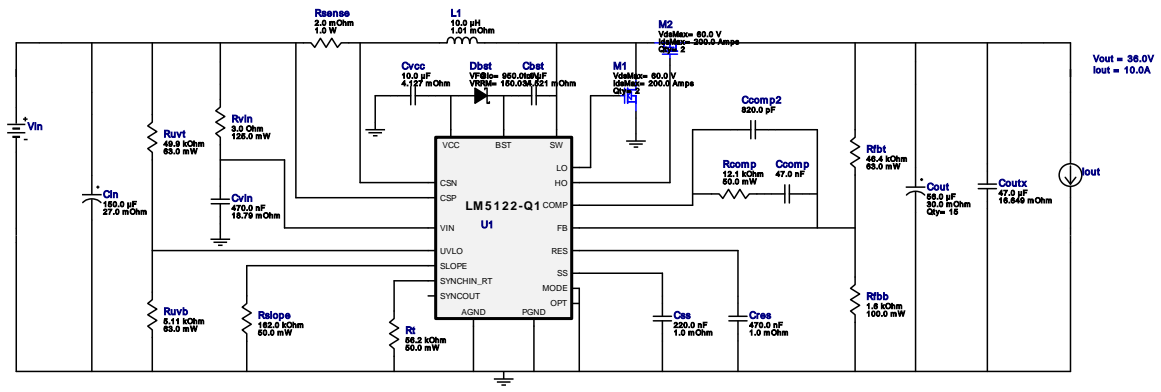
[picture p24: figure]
L1 10.0 µH 1.01 m Ohm; Rfbt 46.4 kOhm; Ruvt 49.9 kOhm; Cout 56.0 µF; 30.0 m Ohm Qty= 15; Rsense 2.0 m Ohm 1.0 W; SYNCOUT; OPT; CSN; CSP; VIN; UVLO; SYNCHIN_RT; AGND; COMP; SLOPE; MODE; RES; PGND; VCC; BST; Ccom p 47.0 nF; VdsMax= 60.0; IdsMax= 200.0; Am ps Qty= 2; Cin 150.0 µF 27.0 m Ohm; Vout = 36.0V Iout = 10.0A Cvcc 10.0 µF 4.127 m Ohm; Css 220.0 nF 1.0 m Ohm; Rslope 162.0 kOhm 50.0 m W; Dbst VF@Io= 950.0 m V; VRRM= 150.0 V; Rcom p 12.1 kOhm 50.0 m W; Ruvb 5.11 kOhm 63.0 m W; Ccom p2 820.0 pF; Cbst 1.0 µF; 34.521 m Ohm; Rvin 3.0 Ohm 125.0 m W; Coutx 47.0 µF 16.649 m Ohm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

Copyright © 2026, Texas Instruments Incorporated | 1 | ti.com/webench

WEBENCH®
Design Report LM5122QMH/NOPB : LM5122QMH/NOPB 15V-22V to 36.00V @ 10A February 8, 2026 11:31:06 GMT-06:00

## WEBENCH ® Design Report

Design : 5 LM5122QMH/NOPB
LM5122QMH/NOPB 15V-22V to 36.00V @ 10A

VinMin = 15.0V
VinMax = 22.0V
Vout = 36.0V
Iout = 10.0A

Device = LM5122QMH/NOPB
Topology = Boost
Created = 2026-01-17 05:07:51.755 BOM Cost = $40.82
BOM Count = 40
Total Pd = 9.25W
1. This regulator device is qualified for Automotive applications. All passives and other components selected in this design may not be qualified for Automotive applications. The user is required to verify that all components in the design meet the qualification and safety requirements for their specific application.View WEBENCH(R) Disclaimer.

### Design Alerts

Component Selection Information
The LM5122-Q1 is qualified for Automotive applications. All passives and other components selected in this design may not be qualified for Automotive applications. The user is required to verify that all components in the design meet the qualification and safety requirements for their specific application.

## Electrical BOM

Name | Manufacturer | Part Number | Properties | Qty Price | Footprint
Cbst | Taiyo Yuden | MSASU21GSB7105KTNA01 (https://ds.yuden.co.jp/TYCOMPAS/ut/detail?pn%3DMSASU21GSB7105KTNA01%26u%3DM) Series= X7R | Cap= 1.0 uF ESR= 34.521 mOhm VDC= 50.0 V IRMS= 1.26652 A
1 | $0.04
| | | | | 0805 7 mm²
Ccomp | Kemet | C0805C473J3GACTU (http://www.kemet.com/docfinder?Partnumber%3DC0805C473J3GACTU) Series= C0G/NP0

Cap= 47.0 nF
VDC= 25.0 V
IRMS= 0.0 A

1 $0.21
0805 7 mm²
Ccomp2 | Samsung Electro- Mechanics | CL05C821JB5NNNC (http://www.samsungsem.com/servlet/FileDownload?type%3Dspec%26file%3DCL05C821JB5NNNC.pdf) Series= C0G/NP0

Cap= 820.0 pF
VDC= 50.0 V
IRMS= 0.0 A

1 $0.01
0402 3 mm²
Cin | Panasonic | EEHZA1V151P Series= ZA

Cap= 150.0 uF
ESR= 27.0 mOhm
VDC= 35.0 V
IRMS= 2.3 A

1 $1.15

SM_RADIAL_8MM 113 mm²
Cout | Panasonic | EEHZA1J560P Series= ZA

Cap= 56.0 uF
ESR= 30.0 mOhm
VDC= 63.0 V
IRMS= 1.8 A

15 $0.93
Panasonic_G 151 mm²
Coutx | TDK | CKG57NX7R1H476M500JH (https://product.tdk.com/ja/search/capacitor/ceramic/mlcc/info?part%5Fno%3DCKG57NX7R1H476M500JH) Series= X7R

Cap= 47.0 uF
ESR= 16.649 mOhm
VDC= 50.0 V
IRMS= 0.0 A

1 $5.07

2220 54 mm²

Cres | Taiyo Yuden | TMK212BJ474KD-T (http://www.yuden.co.jp/ut/product/pdf/djmk%5Fe.pdf) Series= X5R

Cap= 470.0 nF
ESR= 1.0 mOhm
VDC= 20.0 V
IRMS= 0.0 A

1 $0.02
0805 7 mm²

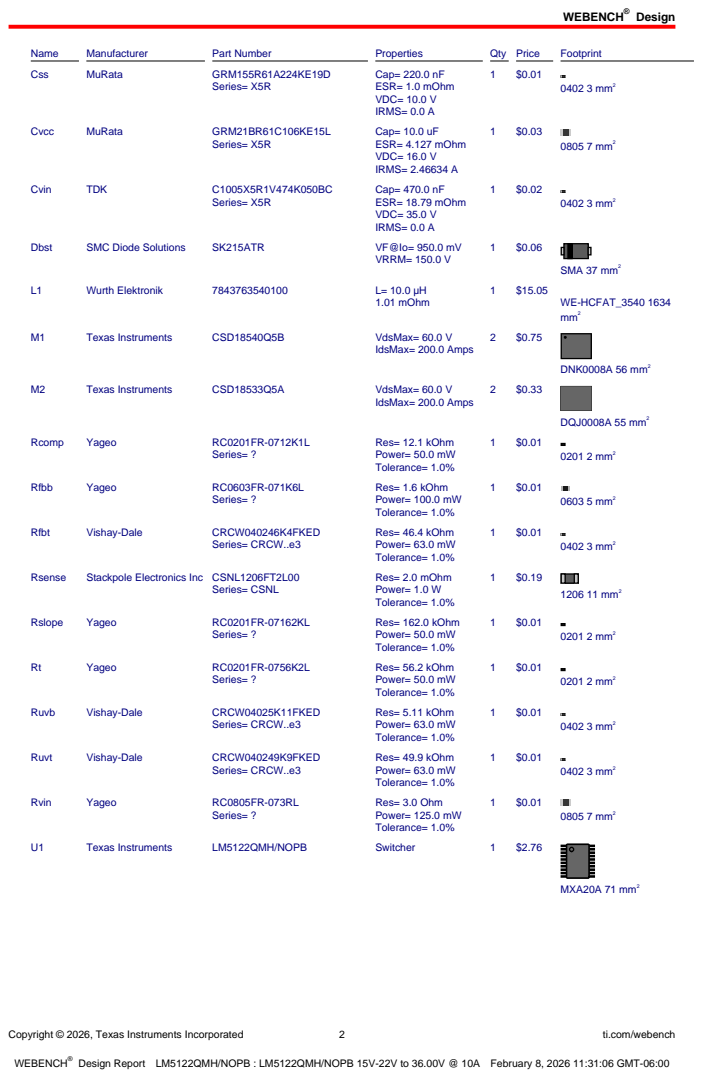
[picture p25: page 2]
Design; Copyright © 2026, Texas Instruments Incorporated; ti.com/webench; Name; Manufacturer; Part Number; Properties; Qty Price; Footprint; Css; MuRata; GRM155R61A224KE19D; Series= X5R; Cap= 220.0 nF ESR= 1.0 mOhm VDC= 10.0 V IRMS= 0.0 A; 0402 3 mm²; Cvcc; GRM21BR61C106KE15L; Cap= 10.0 uF ESR= 4.127 mOhm VDC= 16.0 V IRMS= 2.46634 A; 0805 7 mm²; Cvin; TDK; Cap= 470.0 nF ESR= 18.79 mOhm VDC= 35.0 V IRMS= 0.0 A; Dbst; SMC Diode Solutions; SK215ATR; VRRM= 150.0 V; SMA 37 mm²; Wurth Elektronik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

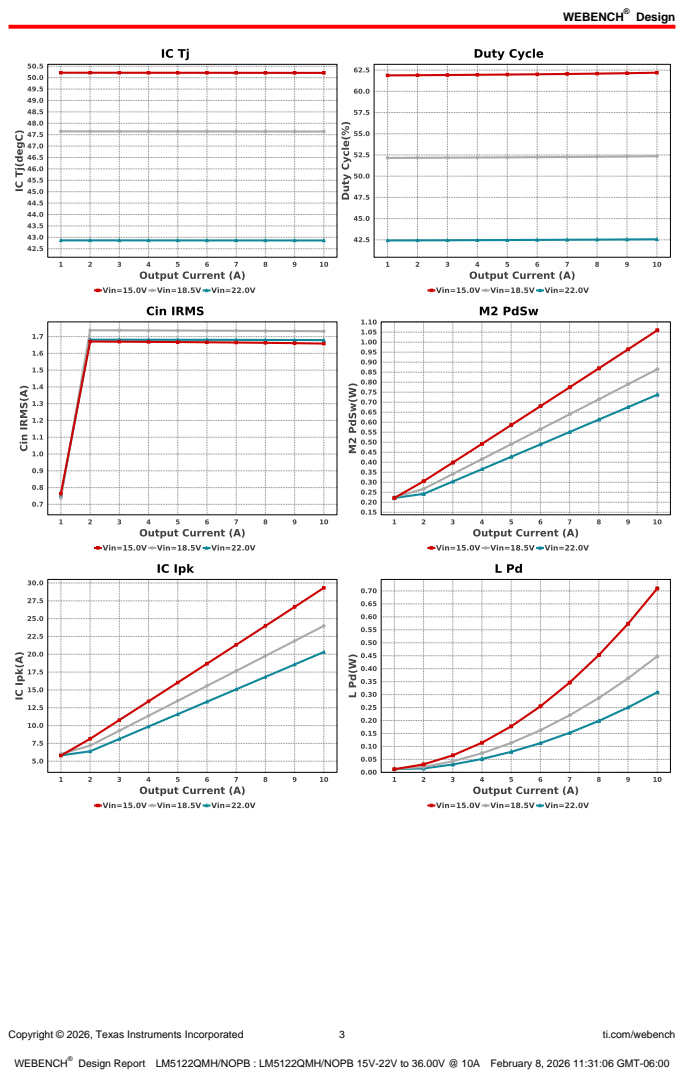
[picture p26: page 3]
Copyright © 2026, Texas Instruments Incorporated; ti.com/webench

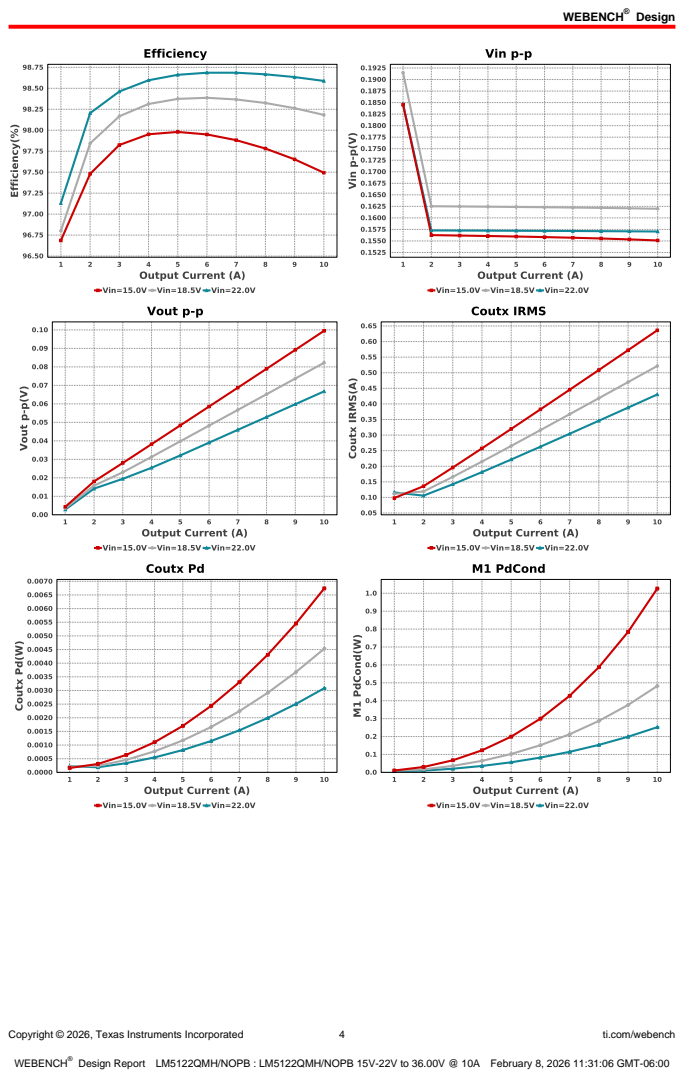
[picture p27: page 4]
Copyright © 2026, Texas Instruments Incorporated; ti.com/webench

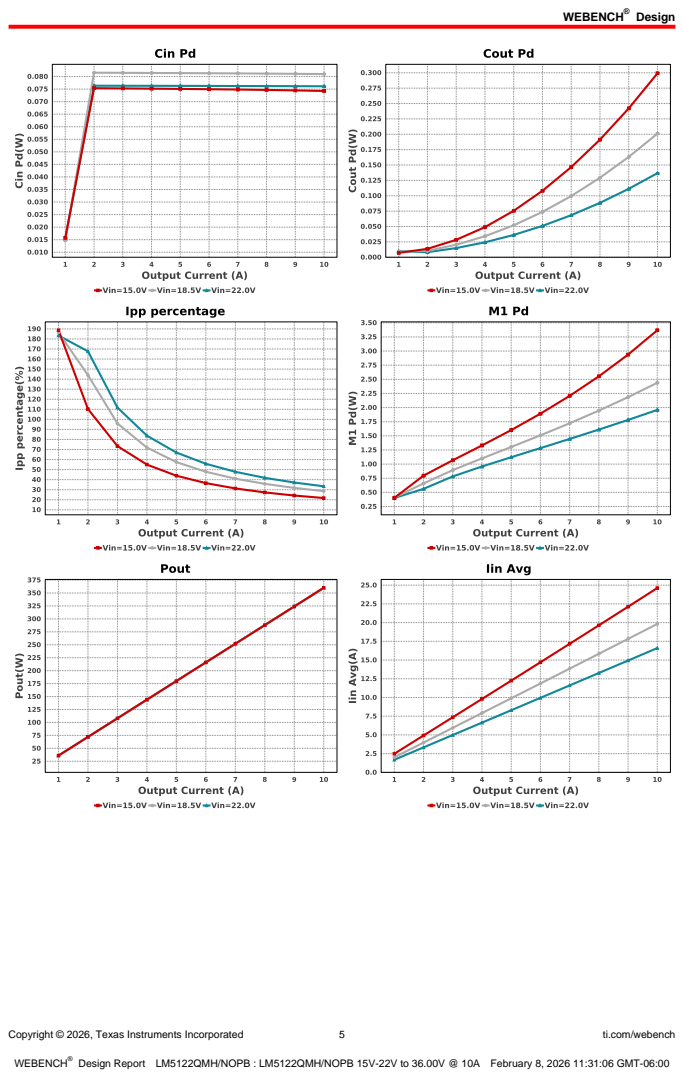
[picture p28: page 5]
Copyright © 2026, Texas Instruments Incorporated; ti.com/webench

Copyright © 2026, Texas Instruments Incorporated; ti.com/webench
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


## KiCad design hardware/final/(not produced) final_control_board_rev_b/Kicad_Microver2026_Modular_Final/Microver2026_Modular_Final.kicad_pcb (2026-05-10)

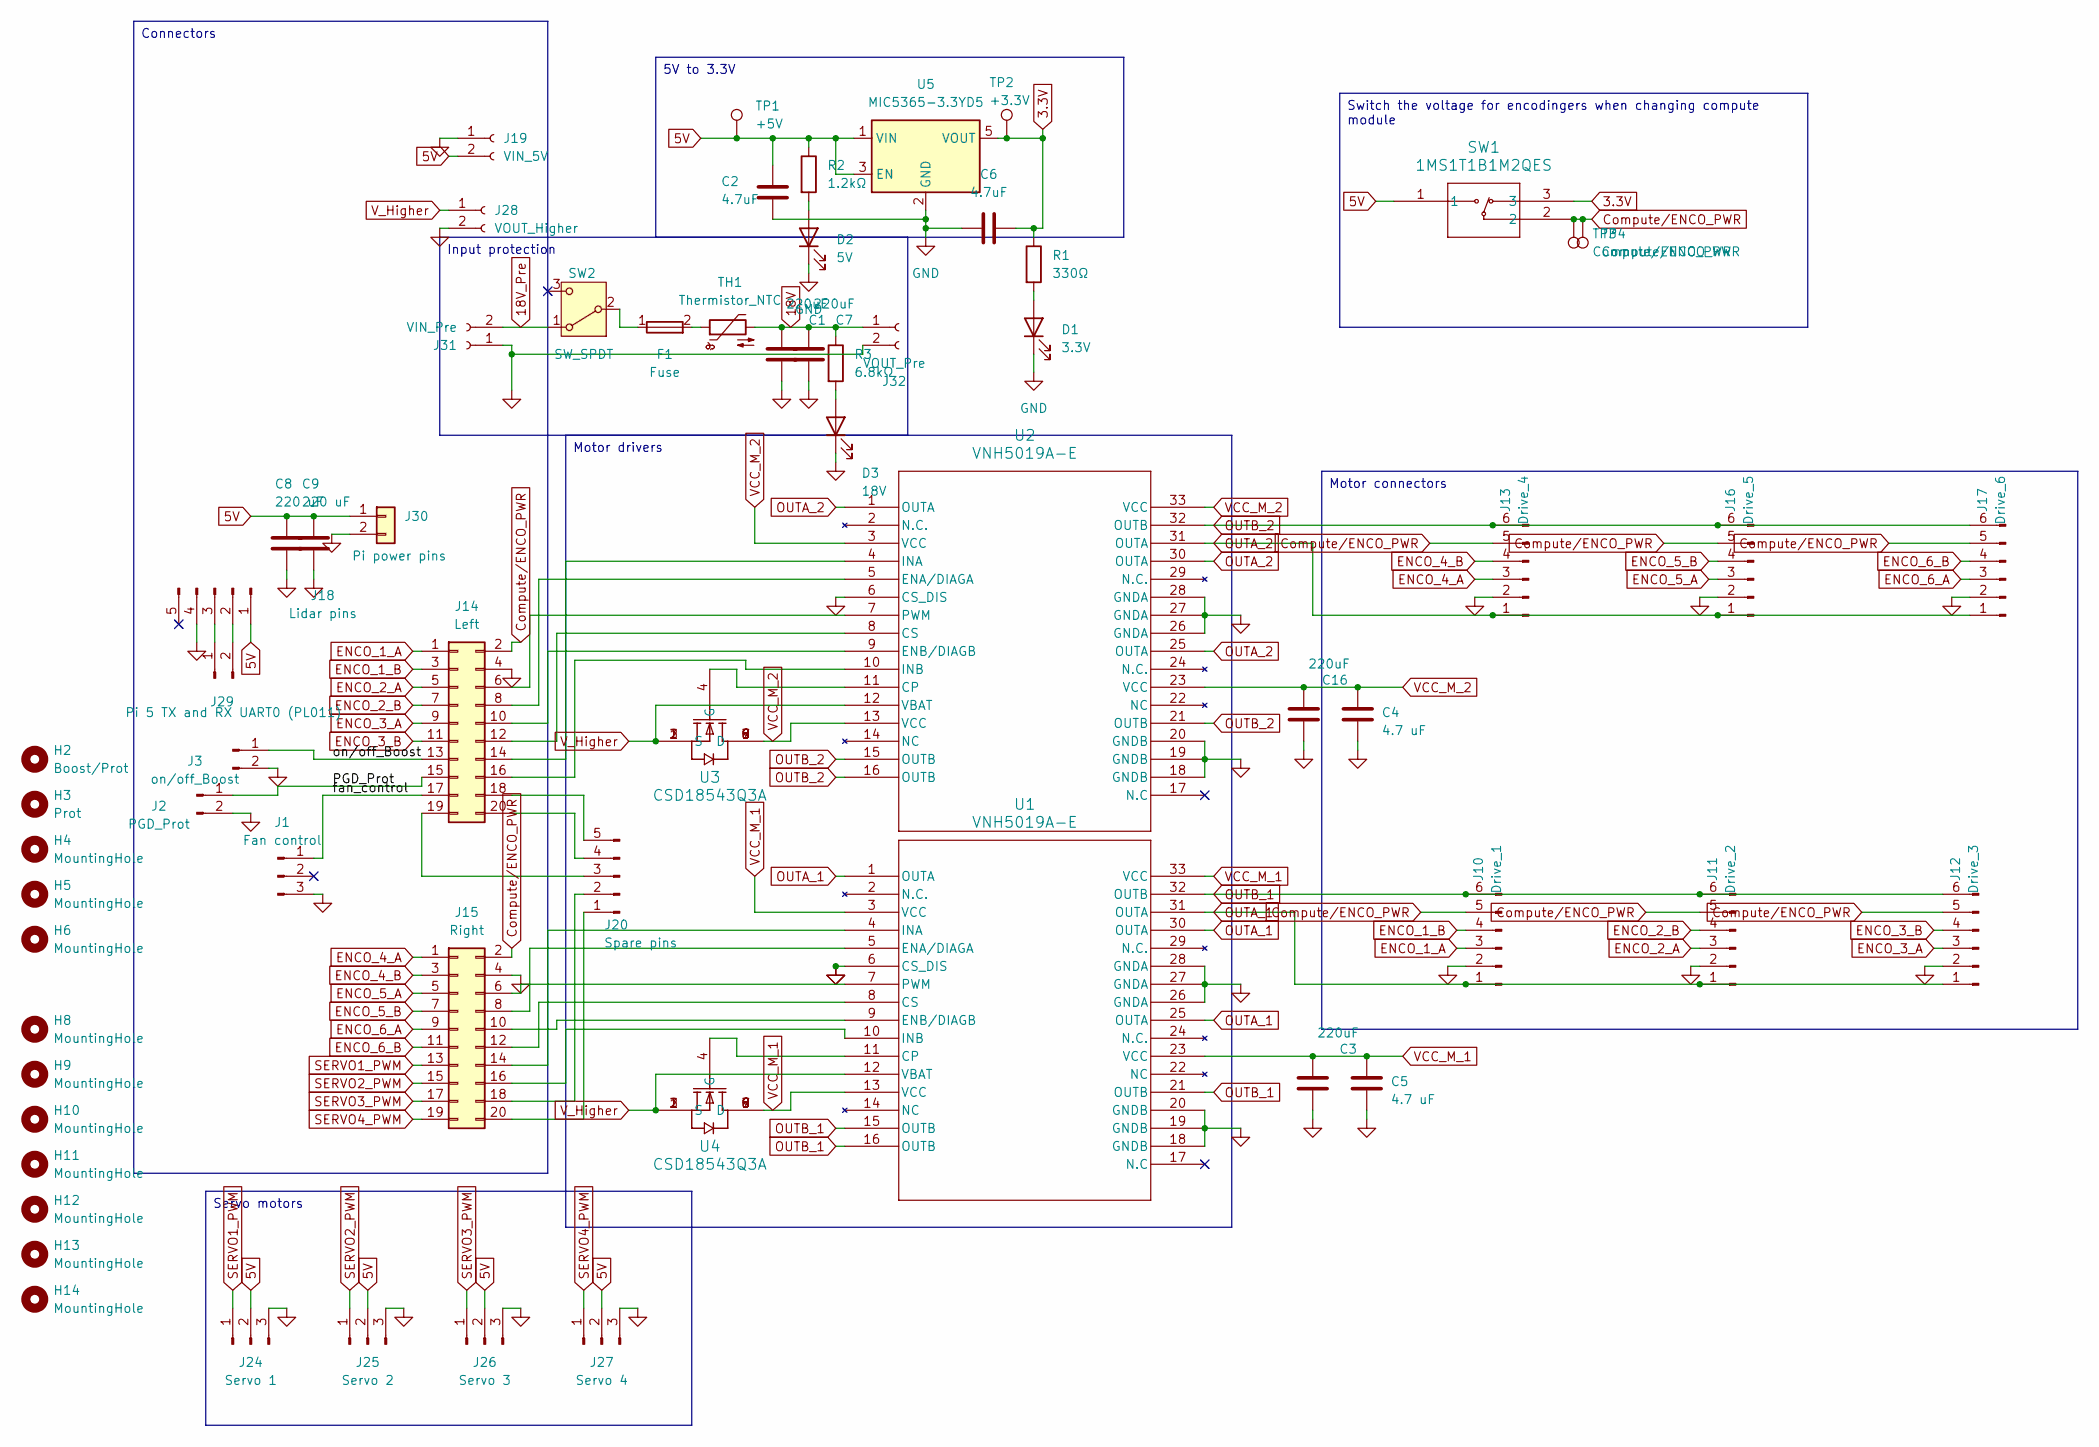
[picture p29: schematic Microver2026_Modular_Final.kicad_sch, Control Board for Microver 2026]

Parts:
C1, C3, C7, C16: 220uF; CP_Radial_D8.0mm_P3.50mm; JLCPCB Part Number C106697
C2, C6: 4.7uF; C_0603_1608Metric; JLCPCB Part Number C19666
C4, C5: 4.7 uF; C_1206_3216Metric; JLCPCB Part Number C29823
C8, C9: 220 uF; CP_Elec_4x5.4; JLCPCB Part Number C116389
D1: 3.3V; LED_0603_1608Metric; JLCPCB Part Number C126319
D2: 5V; LED_0603_1608Metric; JLCPCB Part Number C22371297
D3: 18V; LED_0603_1608Metric; JLCPCB Part Number C22371297
F1: Fuse; Fuse PTF-77; JLCPCB Part Number C717030
H2: Boost/Prot; MountingHole_3.2mm_M3
H3: Prot; MountingHole_3.2mm_M3
H4, H5, H6, H8, H9, H10, H11, H12, H13, H14: MountingHole; MountingHole_3.2mm_M3
J1: Fan control; PinHeader_1x03_P2.54mm_Vertical; JLCPCB Part Number C2937625
J2: PGD_Prot; PinHeader_1x02_P2.54mm_Vertical; JLCPCB Part Number C492401
J3: on/off_Boost; PinHeader_1x02_P2.54mm_Vertical; JLCPCB Part Number C492401
J10: Drive_1; JST_PH_B6B-PH-K_1x06_P2.00mm_Vertical
J11: Drive_2; JST_PH_B6B-PH-K_1x06_P2.00mm_Vertical
J12: Drive_3; JST_PH_B6B-PH-K_1x06_P2.00mm_Vertical
J13: Drive_4; JST_PH_B6B-PH-K_1x06_P2.00mm_Vertical
J14: Left; PinHeader_2x10_P2.54mm_Vertical; JLCPCB Part Number C492427
J15: Right; PinHeader_2x10_P2.54mm_Vertical; JLCPCB Part Number C492427
J16: Drive_5; JST_PH_B6B-PH-K_1x06_P2.00mm_Vertical
J17: Drive_6; JST_PH_B6B-PH-K_1x06_P2.00mm_Vertical
J18: Lidar pins; JST_XH_B5B-XH-AM_1x05_P2.50mm_Vertical
J19: VIN_5V; SolderWire-0.75sqmm_1x02_P7mm_D1.25mm_OD3.5mm; JLCPCB Part Number C8269
J20: Spare pins; PinHeader_1x05_P2.54mm_Vertical; JLCPCB Part Number C492404
J24: Servo 1; PinHeader_1x03_P2.54mm_Vertical; JLCPCB Part Number C2937625
J25: Servo 2; PinHeader_1x03_P2.54mm_Vertical; JLCPCB Part Number C2937625
J26: Servo 3; PinHeader_1x03_P2.54mm_Vertical; JLCPCB Part Number C2937625
J27: Servo 4; PinHeader_1x03_P2.54mm_Vertical; JLCPCB Part Number C2937625
J28: VOUT_Higher; SolderWire-0.75sqmm_1x02_P7mm_D1.25mm_OD3.5mm; JLCPCB Part Number C8269
J29: Pi 5 TX and RX UART0 (PL011); PinHeader_1x02_P2.54mm_Vertical; JLCPCB Part Number C492401
J30: Pi power pins; PinHeader_1x02_P2.54mm_Vertical; JLCPCB Part Number C492401
J31: VIN_Pre; TerminalBlock_MaiXu_MX126-5.0-02P_1x02_P5.00mm; JLCPCB Part Number C8269
J32: VOUT_Pre; SolderWire-0.75sqmm_1x02_P7mm_D1.25mm_OD3.5mm; JLCPCB Part Number C8269
R1: 330Ω; R_0603_1608Metric; JLCPCB Part Number C23138
R2: 1.2kΩ; R_0603_1608Metric; JLCPCB Part Number C22765
R3: 6.8kΩ; R_0603_1608Metric; JLCPCB Part Number C23212
SW1: 1MS1T1B1M2QES; SS-12D10G5_XKB; JLCPCB Part Number C319012
SW2: SW_SPDT; SolderWire-0.5sqmm_1x03_P4.8mm_D0.9mm_OD2.3mm
TH1: Thermistor_NTC; NTC thermistor Microver
TP1: +5V; TestPoint_Pad_1.0x1.0mm
TP2: +3.3V; TestPoint_Pad_1.0x1.0mm
TP3, TP4: Compute/ENCO_PWR; TestPoint_Pad_1.0x1.0mm
U1, U2: VNH5019A-E; SOIC_5019A-E_STM; JLCPCB Part Number C2653552
U3, U4: CSD18543Q3A; DNH0008A; JLCPCB Part Number C840100
U5: MIC5365-3.3YD5; SOT-23-5; JLCPCB Part Number C626098

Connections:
3.3V: C6.2, R1.1, SW1.3, TP2.1, U5.5 (VOUT)
5V: C2.1, C8.1, C9.1, J18.1, J19.2, J24.2, J25.2, J26.2, J27.2, J30.1, R2.1, SW1.1, TP1.1, U5.1 (VIN), U5.3 (EN)
18V: C1.1, C7.1, J32.1, R3.1, TH1.2
18V_Pre: J31.2, SW2.1 (A)
/PGD_Prot: J2.1, J14.15 (Pin_8a)
/fan_control: J1.1, J14.17 (Pin_9a)
/on/off_Boost: J3.1, J14.13 (Pin_7a)
Compute/ENCO_PWR: J10.5, J11.5, J12.5, J13.5, J14.2 (Pin_1b), J15.2 (Pin_1b), J16.5, J17.5, SW1.2, TP3.1, TP4.1
ENCO_1_A: J10.3, J14.1 (Pin_1a)
ENCO_1_B: J10.4, J14.3 (Pin_2a)
ENCO_2_A: J11.3, J14.5 (Pin_3a)
ENCO_2_B: J11.4, J14.7 (Pin_4a)
ENCO_3_A: J12.3, J14.9 (Pin_5a)
ENCO_3_B: J12.4, J14.11 (Pin_6a)
ENCO_4_A: J13.3, J15.1 (Pin_1a)
ENCO_4_B: J13.4, J15.3 (Pin_2a)
ENCO_5_A: J15.5 (Pin_3a), J16.3
ENCO_5_B: J15.7 (Pin_4a), J16.4
ENCO_6_A: J15.9 (Pin_5a), J17.3
ENCO_6_B: J15.11 (Pin_6a), J17.4
GND: C1.2, C2.2, C3.2, C4.2, C5.2, C6.1, C7.2, C8.2, C9.2, C16.2, D1.1 (K), D2.1 (K), D3.1 (K), J1.3, J2.2, J3.2, J10.2, J11.2, J12.2, J13.2, J14.4 (Pin_2b), J15.4 (Pin_2b), J16.2, J17.2, J18.4, J19.1, J24.3, J25.3, J26.3, J27.3, J28.2, J30.2, J31.1, J32.2, U1.6 (CS_DIS), U1.18 (GNDB), U1.19 (GNDB), U1.20 (GNDB), U1.26 (GNDA), U1.27 (GNDA), U1.28 (GNDA), U2.6 (CS_DIS), U2.18 (GNDB), U2.19 (GNDB), U2.20 (GNDB), U2.26 (GNDA), U2.27 (GNDA), U2.28 (GNDA), U5.2 (GND)
unnamed: D1.2 (A), R1.2
unnamed: D2.2 (A), R2.2
unnamed: D3.2 (A), R3.2
unnamed: F1.2, TH1.1
unnamed: J14.6 (Pin_3b), U2.7 (PWM)
unnamed: J14.8 (Pin_4b), U2.5 (ENA/DIAGA)
unnamed: J14.10 (Pin_5b), U2.9 (ENB/DIAGB)
unnamed: J14.12 (Pin_6b), U2.8 (CS)
unnamed: J14.14 (Pin_7b), U2.4 (INA)
unnamed: J14.16 (Pin_8b), U2.10 (INB)
unnamed: J14.18 (Pin_9b), J20.5
unnamed: J14.19 (Pin_10a), J20.3
unnamed: J14.20 (Pin_10b), J20.4
unnamed: J15.6 (Pin_3b), U1.7 (PWM)
unnamed: J15.8 (Pin_4b), U1.5 (ENA/DIAGA)
unnamed: J15.10 (Pin_5b), U1.9 (ENB/DIAGB)
unnamed: J15.12 (Pin_6b), U1.8 (CS)
unnamed: J15.14 (Pin_7b), U1.4 (INA)
unnamed: J15.16 (Pin_8b), U1.10 (INB)
unnamed: J15.18 (Pin_9b), J20.2
unnamed: J15.20 (Pin_10b), J20.1
unnamed: J18.2, J29.2
unnamed: J18.3, J29.1
unnamed: F1.1, SW2.2 (B)
unnamed: U1.11 (CP), U4.4 (G)
unnamed: U2.11 (CP), U3.4 (G)
OUTA_1: J10.1, J11.1, J12.1, U1.1 (OUTA), U1.25 (OUTA), U1.30 (OUTA), U1.31 (OUTA)
OUTA_2: J13.1, J16.1, J17.1, U2.1 (OUTA), U2.25 (OUTA), U2.30 (OUTA), U2.31 (OUTA)
OUTB_1: J10.6, J11.6, J12.6, U1.15 (OUTB), U1.16 (OUTB), U1.21 (OUTB), U1.32 (OUTB)
OUTB_2: J13.6, J16.6, J17.6, U2.15 (OUTB), U2.16 (OUTB), U2.21 (OUTB), U2.32 (OUTB)
SERVO1_PWM: J15.13 (Pin_7a), J24.1
SERVO2_PWM: J15.15 (Pin_8a), J25.1
SERVO3_PWM: J15.17 (Pin_9a), J26.1
SERVO4_PWM: J15.19 (Pin_10a), J27.1
VCC_M_1: C3.1, C5.1, U1.3 (VCC), U1.13 (VCC), U1.23 (VCC), U1.33 (VCC), U4.5 (D), U4.6 (D), U4.7 (D), U4.8 (D), U4.9 (D)
VCC_M_2: C4.1, C16.1, U2.3 (VCC), U2.13 (VCC), U2.23 (VCC), U2.33 (VCC), U3.5 (D), U3.6 (D), U3.7 (D), U3.8 (D), U3.9 (D)
V_Higher: J28.1, U1.12 (VBAT), U2.12 (VBAT), U3.1 (S), U3.2 (S), U3.3 (S), U4.1 (S), U4.2 (S), U4.3 (S)

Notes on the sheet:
Motor drivers
Input protection
Servo motors
Motor connectors
5V to 3.3V
Switch the voltage for encodingers when changing compute module
Connectors

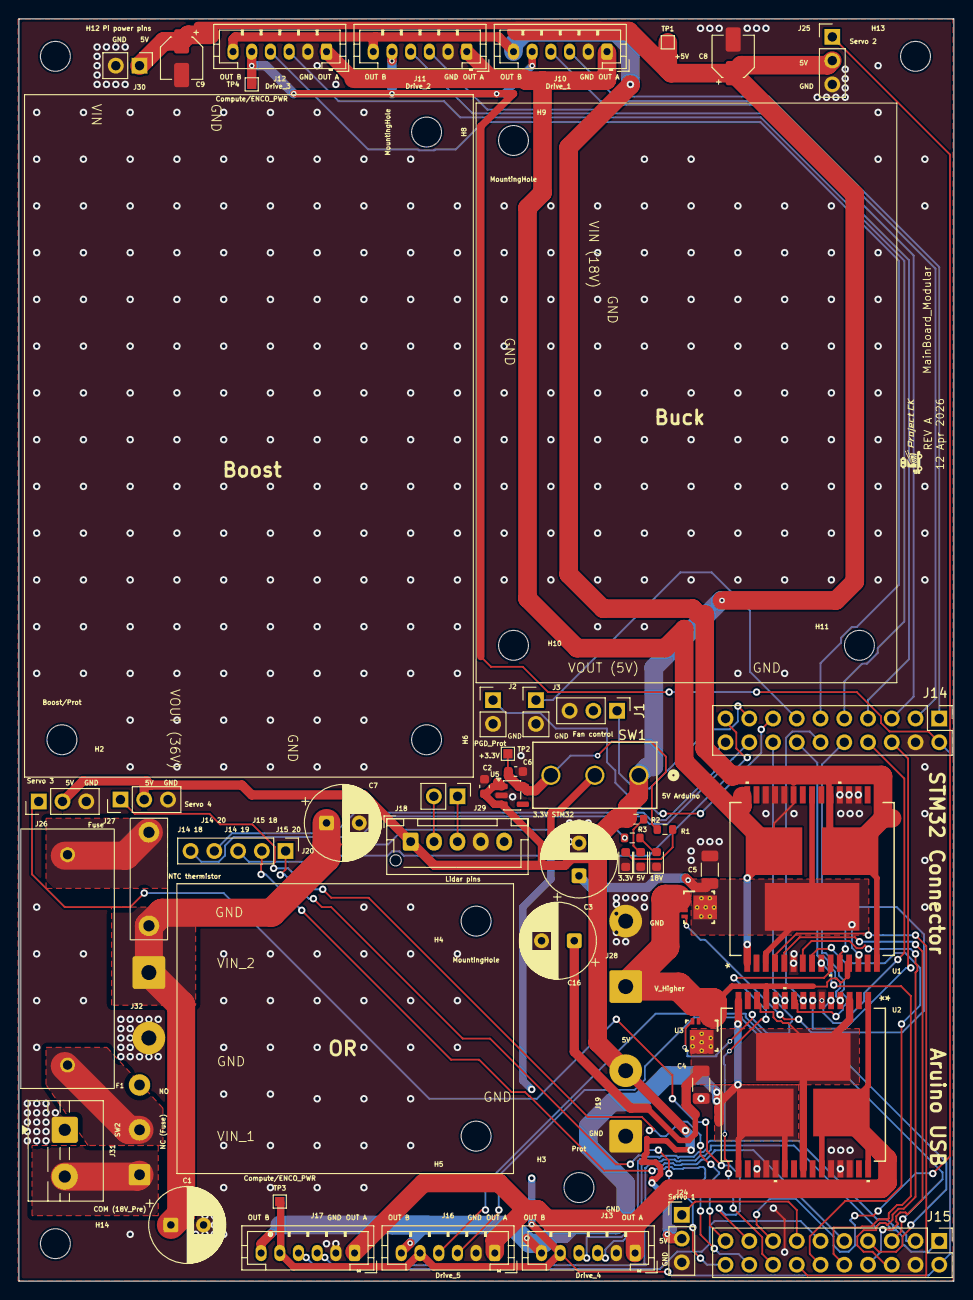
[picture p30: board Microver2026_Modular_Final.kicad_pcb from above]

Board: 4 copper layers, 100.0 x 135.0 mm, 64 parts (0 on the bottom side), 58 nets.

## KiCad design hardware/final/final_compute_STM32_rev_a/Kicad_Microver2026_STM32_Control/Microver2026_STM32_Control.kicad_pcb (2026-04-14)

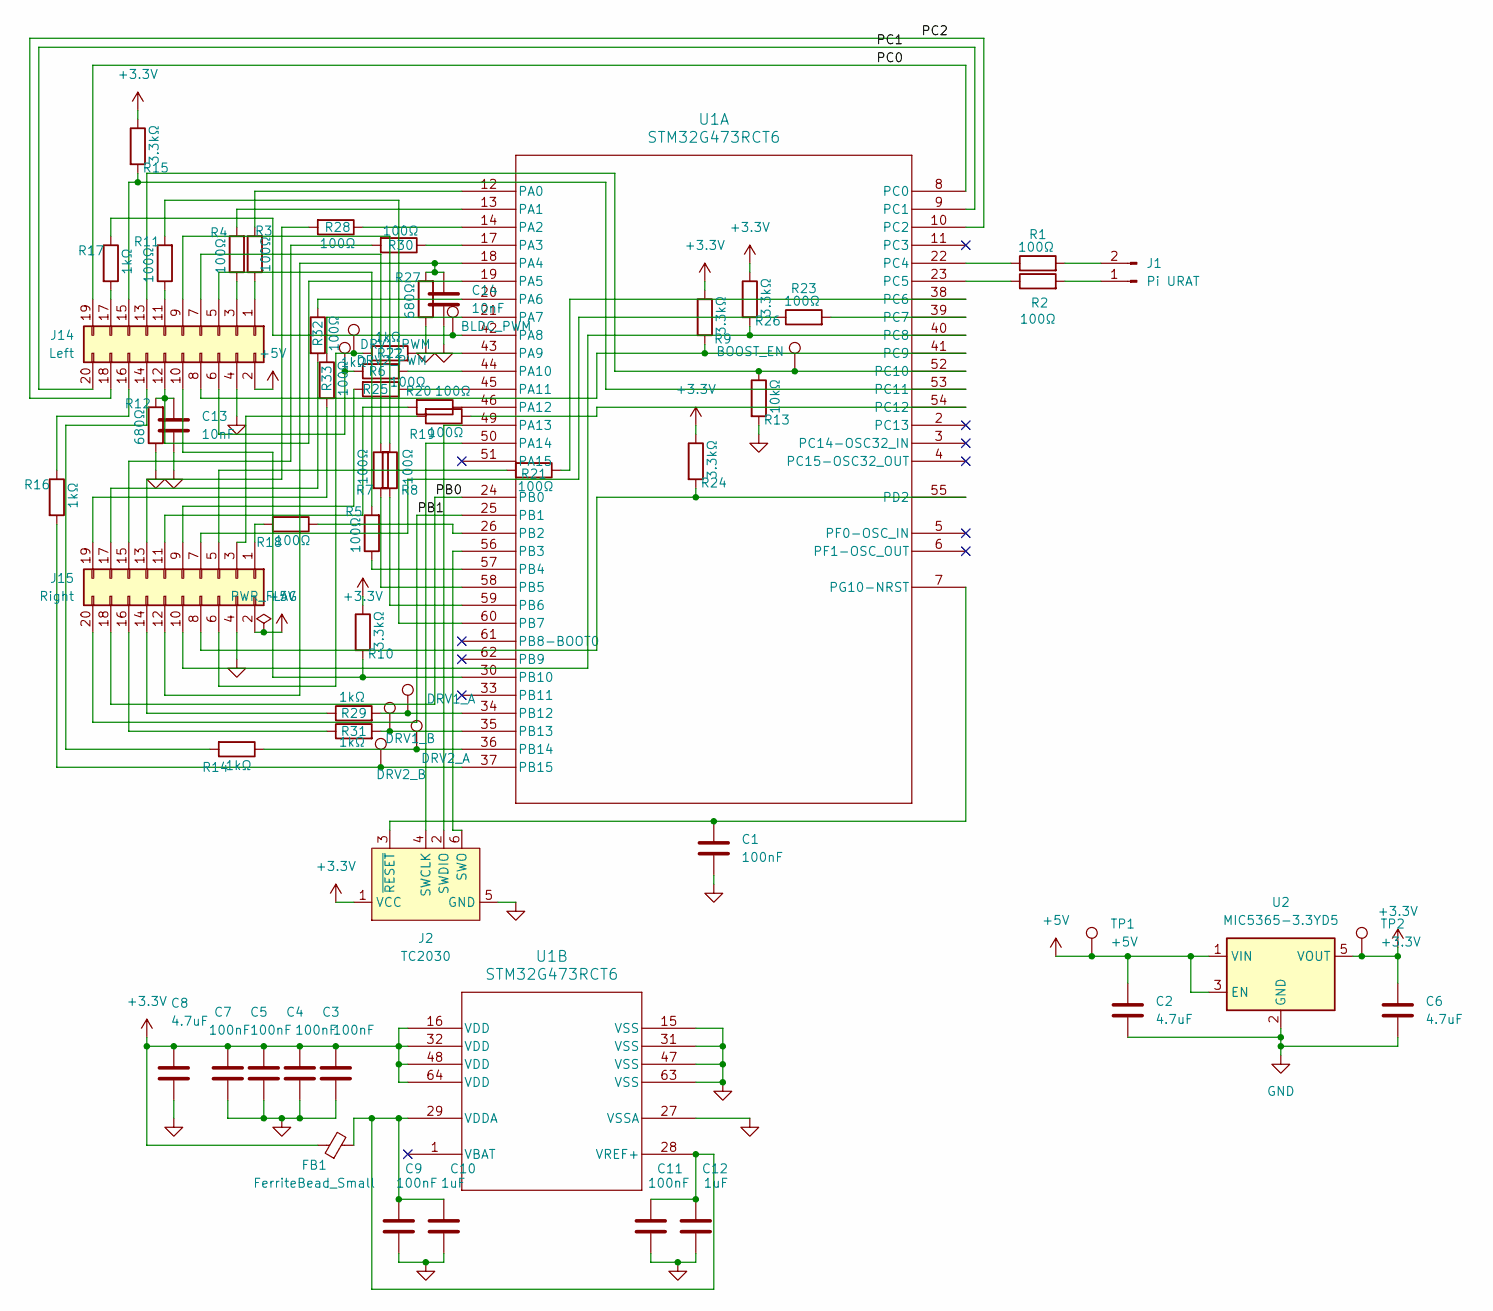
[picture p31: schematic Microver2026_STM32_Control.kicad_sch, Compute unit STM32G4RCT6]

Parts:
C1, C3, C4, C5, C7, C9, C11: 100nF; C_0603_1608Metric; JLCPCB part number C14663
C2, C6, C8: 4.7uF; C_0603_1608Metric; JLCPCB part number C19666
C10, C12: 1uF; C_0603_1608Metric; JLCPCB part number C15849
C13, C14: 10nF; C_0603_1608Metric; JLCPCB part number C57112
FB1: FerriteBead_Small; R_0603_1608Metric; JLCPCB part number C14709
J1: Pi URAT; PinHeader_1x02_P2.54mm_Vertical; JLCPCB part number C492401
J2: TC2030; Tag-Connect_TC2030-IDC-FP_2x03_P1.27mm_Vertical
J14: Left; PinHeader_2x10_P2.54mm_Vertical
J15: Right; PinHeader_2x10_P2.54mm_Vertical
R1, R2, R3, R4, R5, R7, R8, R11, R18, R19, R20, R21, R23, R25, R28, R30, R32, R33: 100Ω; R_0603_1608Metric; JLCPCB part number C22775
R6, R14, R16, R17, R22, R29, R31: 1kΩ; R_0603_1608Metric; JLCPCB part number C21190
R9, R10, R15, R24, R26: 3.3kΩ; R_0603_1608Metric; JLCPCB part number C22978
R12, R27: 680Ω; R_0603_1608Metric; JLCPCB part number C23228
R13: 10kΩ; R_0603_1608Metric; JLCPCB part number C25804
TP1: +5V; TestPoint_Pad_1.0x1.0mm
TP2: +3.3V; TestPoint_Pad_1.0x1.0mm
TP3: BLDC_PWM; TestPoint_Pad_1.0x1.0mm
TP4: DRV1_A; TestPoint_Pad_1.0x1.0mm
TP5: DRV1_B; TestPoint_Pad_1.0x1.0mm
TP6: DRV2_A; TestPoint_Pad_1.0x1.0mm
TP7: DRV1_PWM; TestPoint_Pad_1.0x1.0mm
TP8: DRV2_B; TestPoint_Pad_1.0x1.0mm
TP12: DRV2_PWM; TestPoint_Pad_1.0x1.0mm
TP15: BOOST_EN; TestPoint_Pad_1.0x1.0mm
U1: STM32G473RCT6; LQFP64-10x10mm; JLCPCB part number C529361
U2: MIC5365-3.3YD5; SOT-23-5; JLCPCB part number C626098

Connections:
+3.3V: C3.1, C4.1, C5.1, C6.1, C7.1, C8.1, FB1.1, J2.1 (VCC), R9.1, R10.1, R15.1, R24.1, R26.1, TP2.1, U1.16 (VDD), U1.32 (VDD), U1.48 (VDD), U1.64 (VDD), U2.5 (VOUT)
+5V: C2.1, J14.2 (Pin_1b), J15.2 (Pin_1b), TP1.1, U2.1 (VIN), U2.3 (EN)
/PB0: J15.18 (Pin_9b), U1.24 (PB0)
/PB1: J15.20 (Pin_10b), U1.25 (PB1)
/PC0: J14.19 (Pin_10a), U1.8 (PC0)
/PC1: J14.20 (Pin_10b), U1.9 (PC1)
/PC2: J14.18 (Pin_9b), U1.10 (PC2)
GND: C1.2, C2.2, C3.2, C4.2, C5.2, C6.2, C7.2, C8.2, C9.2, C10.2, C11.2, C12.2, C13.2, C14.2, J2.5 (GND), J14.4 (Pin_2b), J15.4 (Pin_2b), R12.1, R13.2, R27.1, U1.15 (VSS), U1.27 (VSSA), U1.31 (VSS), U1.47 (VSS), U1.63 (VSS), U2.2 (GND)
unnamed: J1.1, R2.2
unnamed: J1.2, R1.2
unnamed: J2.4 (SWCLK), U1.50 (PA14)
unnamed: J2.2 (SWDIO), U1.49 (PA13)
unnamed: J2.6 (SWO), U1.56 (PB3)
unnamed: C1.1, J2.3 (~RESET), U1.7 (PG10-NRST)
unnamed: J14.1 (Pin_1a), R3.1
unnamed: J14.3 (Pin_2a), R4.1
unnamed: J14.5 (Pin_3a), R5.2
unnamed: J14.6 (Pin_3b), R6.2, TP12.1
unnamed: J14.7 (Pin_4a), R7.1
unnamed: J14.8 (Pin_4b), R9.2, U1.41 (PC9)
unnamed: J14.9 (Pin_5a), R8.1
unnamed: J14.10 (Pin_5b), R10.2, U1.30 (PB10)
unnamed: J14.11 (Pin_6a), R11.1
unnamed: C13.1, J14.12 (Pin_6b), R12.2, U1.19 (PA5)
unnamed: J14.13 (Pin_7a), R13.1, TP15.1, U1.52 (PC10)
unnamed: J14.14 (Pin_7b), R14.2
unnamed: J14.15 (Pin_8a), R15.2, U1.53 (PC11)
unnamed: J14.16 (Pin_8b), R16.1
unnamed: J14.17 (Pin_9a), R17.2
unnamed: J15.1 (Pin_1a), R18.2
unnamed: J15.3 (Pin_2a), R19.2
unnamed: J15.5 (Pin_3a), R21.2
unnamed: J15.6 (Pin_3b), R22.1, TP7.1
unnamed: J15.7 (Pin_4a), R23.1
unnamed: J15.8 (Pin_4b), R24.2, U1.55 (PD2)
unnamed: J15.9 (Pin_5a), R25.2
unnamed: J15.10 (Pin_5b), R26.2, U1.40 (PC8)
unnamed: J15.11 (Pin_6a), R20.2
unnamed: C14.1, J15.12 (Pin_6b), R27.2, U1.18 (PA4)
unnamed: J15.13 (Pin_7a), R28.2
unnamed: J15.14 (Pin_7b), R29.1
unnamed: J15.15 (Pin_8a), R30.2
unnamed: J15.16 (Pin_8b), R31.1
unnamed: J15.17 (Pin_9a), R32.2
unnamed: J15.19 (Pin_10a), R33.2
unnamed: R3.2, U1.12 (PA0)
unnamed: R4.2, U1.13 (PA1)
unnamed: R28.1, U1.14 (PA2)
unnamed: R30.1, U1.17 (PA3)
unnamed: R32.1, U1.20 (PA6)
unnamed: R33.1, U1.21 (PA7)
unnamed: R17.1, TP3.1, U1.42 (PA8)
unnamed: R22.2, U1.43 (PA9)
unnamed: R6.1, U1.44 (PA10)
unnamed: R25.1, U1.45 (PA11)
unnamed: R20.1, U1.46 (PA12)
unnamed: R18.1, U1.26 (PB2)
unnamed: R5.1, U1.57 (PB4)
unnamed: R7.2, U1.58 (PB5)
unnamed: R8.2, U1.59 (PB6)
unnamed: R11.2, U1.60 (PB7)
unnamed: R29.2, TP4.1, U1.34 (PB12)
unnamed: R31.2, TP5.1, U1.35 (PB13)
unnamed: R14.1, TP6.1, U1.36 (PB14)
unnamed: R16.2, TP8.1, U1.37 (PB15)
unnamed: R1.1, U1.22 (PC4)
unnamed: R2.1, U1.23 (PC5)
unnamed: R21.1, U1.38 (PC6)
unnamed: R23.2, U1.39 (PC7)
unnamed: R19.1, U1.54 (PC12)
unnamed: C9.1, C10.1, C11.1, C12.1, FB1.2, U1.28 (VREF+), U1.29 (VDDA)

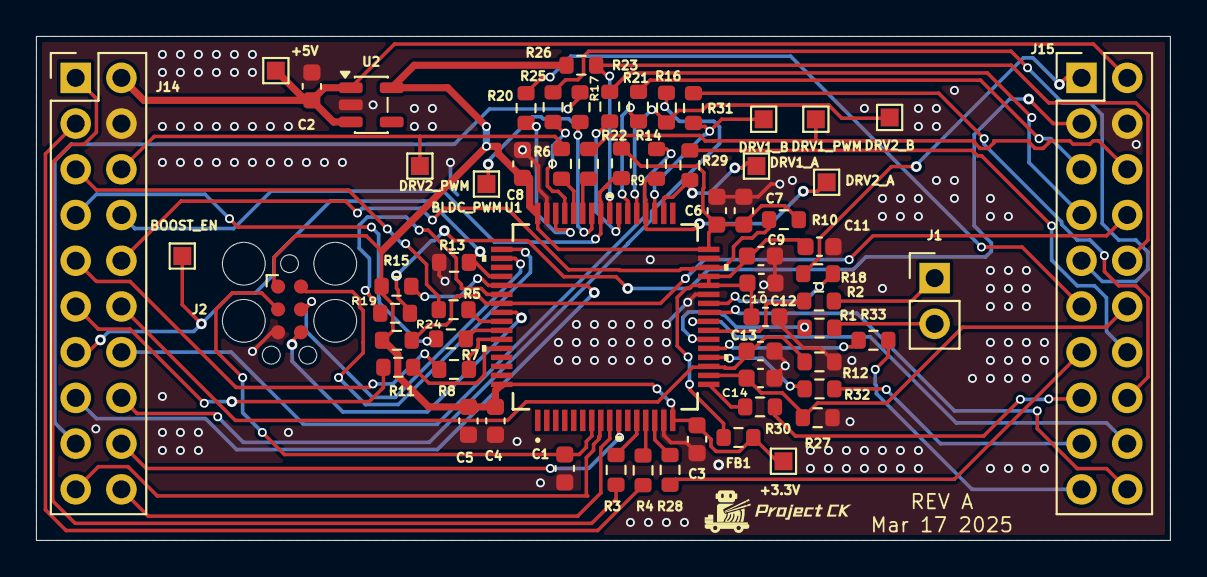
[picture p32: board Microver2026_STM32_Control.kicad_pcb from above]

Board: 4 copper layers, 63.0 x 28.0 mm, 64 parts (0 on the bottom side), 71 nets.

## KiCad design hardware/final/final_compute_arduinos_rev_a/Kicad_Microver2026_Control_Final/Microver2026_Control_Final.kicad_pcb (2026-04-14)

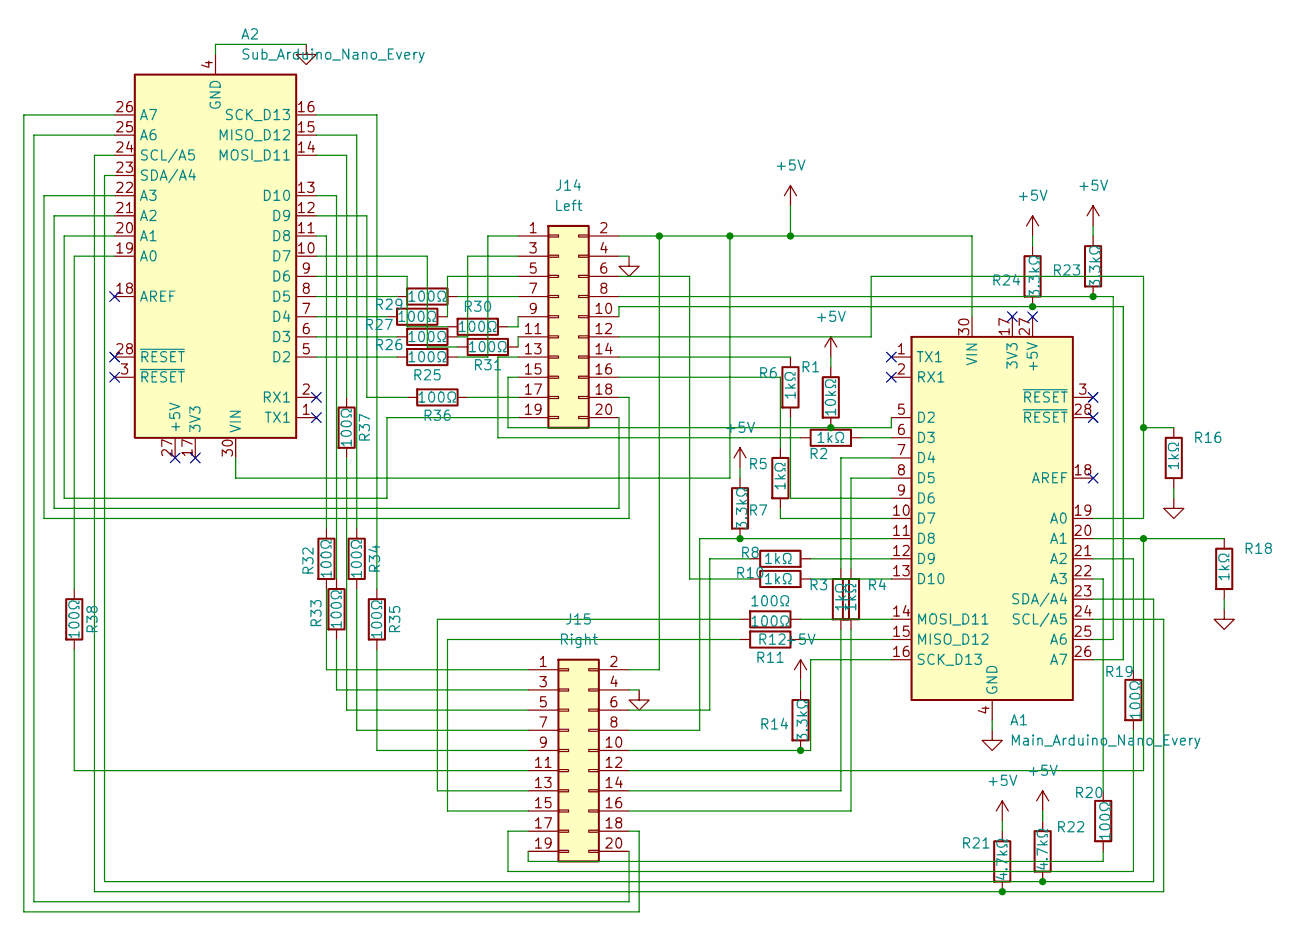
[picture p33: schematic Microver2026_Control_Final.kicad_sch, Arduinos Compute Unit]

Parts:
A1: Main_Arduino_Nano_Every; Arduino_Nano
A2: Sub_Arduino_Nano_Every; Arduino_Nano
J14: Left; PinHeader_2x10_P2.54mm_Vertical
J15: Right; PinHeader_2x10_P2.54mm_Vertical
R1: 10kΩ; R_0603_1608Metric; JLCPCB part number C25804
R2, R3, R4, R5, R6, R8, R10, R16, R18: 1kΩ; R_0603_1608Metric; JLCPCB part number C21190
R7, R14, R23, R24: 3.3kΩ; R_0603_1608Metric; JLCPCB part number C22978
R11, R12, R19, R20, R25, R26, R27, R29, R30, R31, R32, R33, R34, R35, R36, R37, R38: 100Ω; R_0603_1608Metric; JLCPCB part number C22775
R21, R22: 4.7kΩ; R_0603_1608Metric; JLCPCB part number C23162

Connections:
+5V: A1.30 (VIN), A2.30 (VIN), J14.2 (Pin_1b), J15.2 (Pin_1b), R1.1, R7.1, R14.1, R21.1, R22.1, R23.1, R24.1
GND: A1.4 (GND), A1.29 (GND), A2.4 (GND), A2.29 (GND), J14.4 (Pin_2b), J15.4 (Pin_2b), R16.2, R18.2
unnamed: A1.19 (A0), J14.12 (Pin_6b), R16.1
unnamed: A1.20 (A1), J15.12 (Pin_6b), R18.1
unnamed: A1.21 (A2), R19.1
unnamed: A1.22 (A3), R20.1
unnamed: A1.25 (A6), J14.8 (Pin_4b), R23.2
unnamed: A1.26 (A7), J14.10 (Pin_5b), R24.2
unnamed: A1.5 (D2), J14.15 (Pin_8a), R1.2
unnamed: A1.6 (D3), R2.2
unnamed: A1.7 (D4), R3.1
unnamed: A1.8 (D5), R4.1
unnamed: A1.9 (D6), R6.2
unnamed: A1.10 (D7), R5.2
unnamed: A1.11 (D8), J15.8 (Pin_4b), R7.2
unnamed: A1.12 (D9), R8.2
unnamed: A1.13 (D10), R10.2
unnamed: A1.15 (MISO_D12), R12.1
unnamed: A1.14 (MOSI_D11), R11.1
unnamed: A1.16 (SCK_D13), J15.10 (Pin_5b), R14.2
unnamed: A1.24 (SCL/A5), A2.24 (SCL/A5), R21.2
unnamed: A1.23 (SDA/A4), A2.23 (SDA/A4), R22.2
unnamed: A2.19 (A0), R38.1
unnamed: A2.20 (A1), J14.19 (Pin_10a)
unnamed: A2.21 (A2), J14.20 (Pin_10b)
unnamed: A2.22 (A3), J14.18 (Pin_9b)
unnamed: A2.25 (A6), J15.20 (Pin_10b)
unnamed: A2.26 (A7), J15.18 (Pin_9b)
unnamed: A2.5 (D2), R25.2
unnamed: A2.6 (D3), R26.2
unnamed: A2.7 (D4), R27.2
unnamed: A2.8 (D5), R29.2
unnamed: A2.9 (D6), R30.2
unnamed: A2.10 (D7), R31.2
unnamed: A2.11 (D8), R32.1
unnamed: A2.12 (D9), R36.2
unnamed: A2.13 (D10), R33.1
unnamed: A2.15 (MISO_D12), R34.1
unnamed: A2.14 (MOSI_D11), R37.1
unnamed: A2.16 (SCK_D13), R35.1
unnamed: J14.1 (Pin_1a), R25.1
unnamed: J14.3 (Pin_2a), R26.1
unnamed: J14.5 (Pin_3a), R27.1
unnamed: J14.6 (Pin_3b), R10.1
unnamed: J14.7 (Pin_4a), R29.1
unnamed: J14.9 (Pin_5a), R30.1
unnamed: J14.11 (Pin_6a), R31.1
unnamed: J14.13 (Pin_7a), R2.1
unnamed: J14.14 (Pin_7b), R6.1
unnamed: J14.16 (Pin_8b), R5.1
unnamed: J14.17 (Pin_9a), R36.1
unnamed: J15.1 (Pin_1a), R32.2
unnamed: J15.3 (Pin_2a), R33.2
unnamed: J15.5 (Pin_3a), R37.2
unnamed: J15.6 (Pin_3b), R8.1
unnamed: J15.7 (Pin_4a), R34.2
unnamed: J15.9 (Pin_5a), R35.2
unnamed: J15.11 (Pin_6a), R38.2
unnamed: J15.13 (Pin_7a), R11.2
unnamed: J15.14 (Pin_7b), R3.2
unnamed: J15.15 (Pin_8a), R12.2
unnamed: J15.16 (Pin_8b), R4.2
unnamed: J15.17 (Pin_9a), R19.2
unnamed: J15.19 (Pin_10a), R20.2

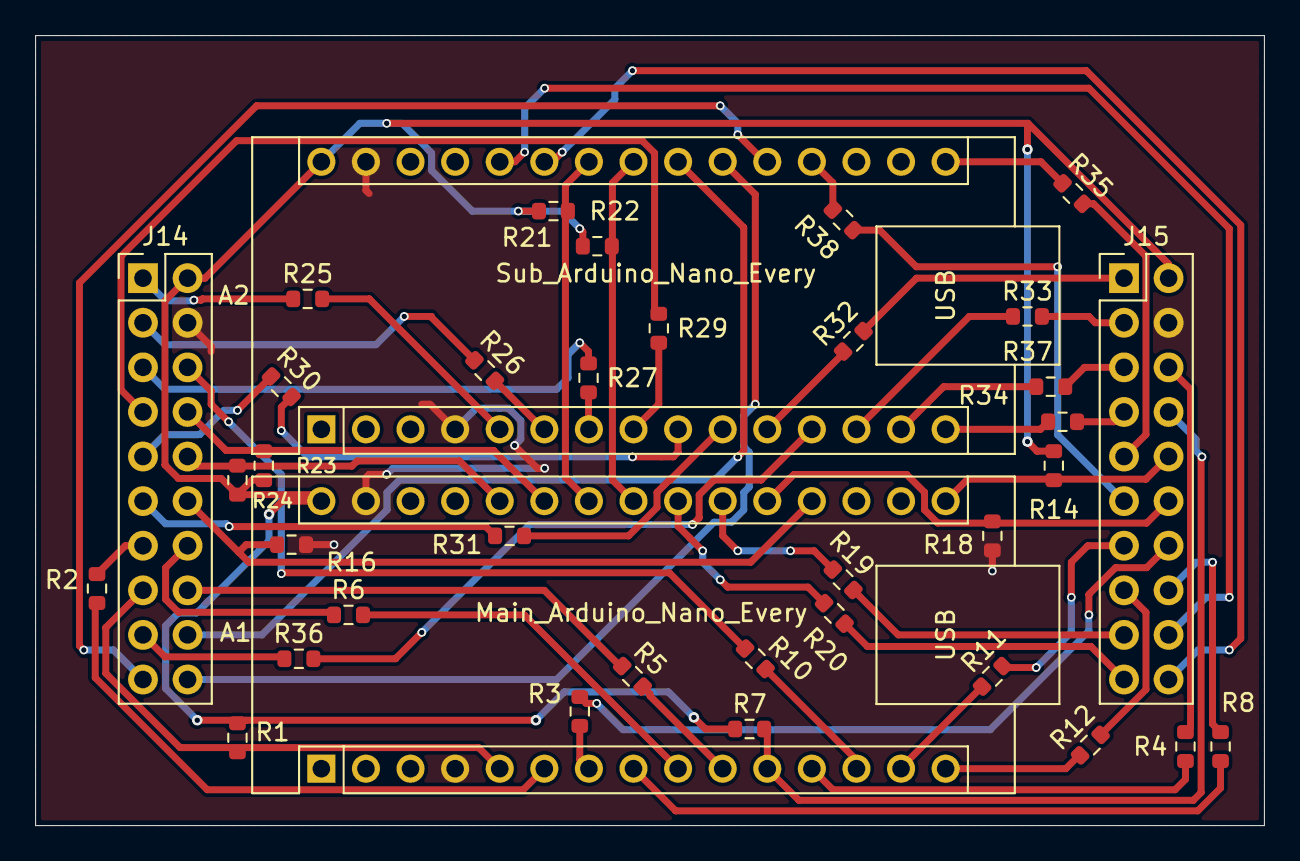
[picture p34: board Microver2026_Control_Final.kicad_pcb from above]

Board: 4 copper layers, 70.0 x 45.0 mm, 37 parts (0 on the bottom side), 64 nets.

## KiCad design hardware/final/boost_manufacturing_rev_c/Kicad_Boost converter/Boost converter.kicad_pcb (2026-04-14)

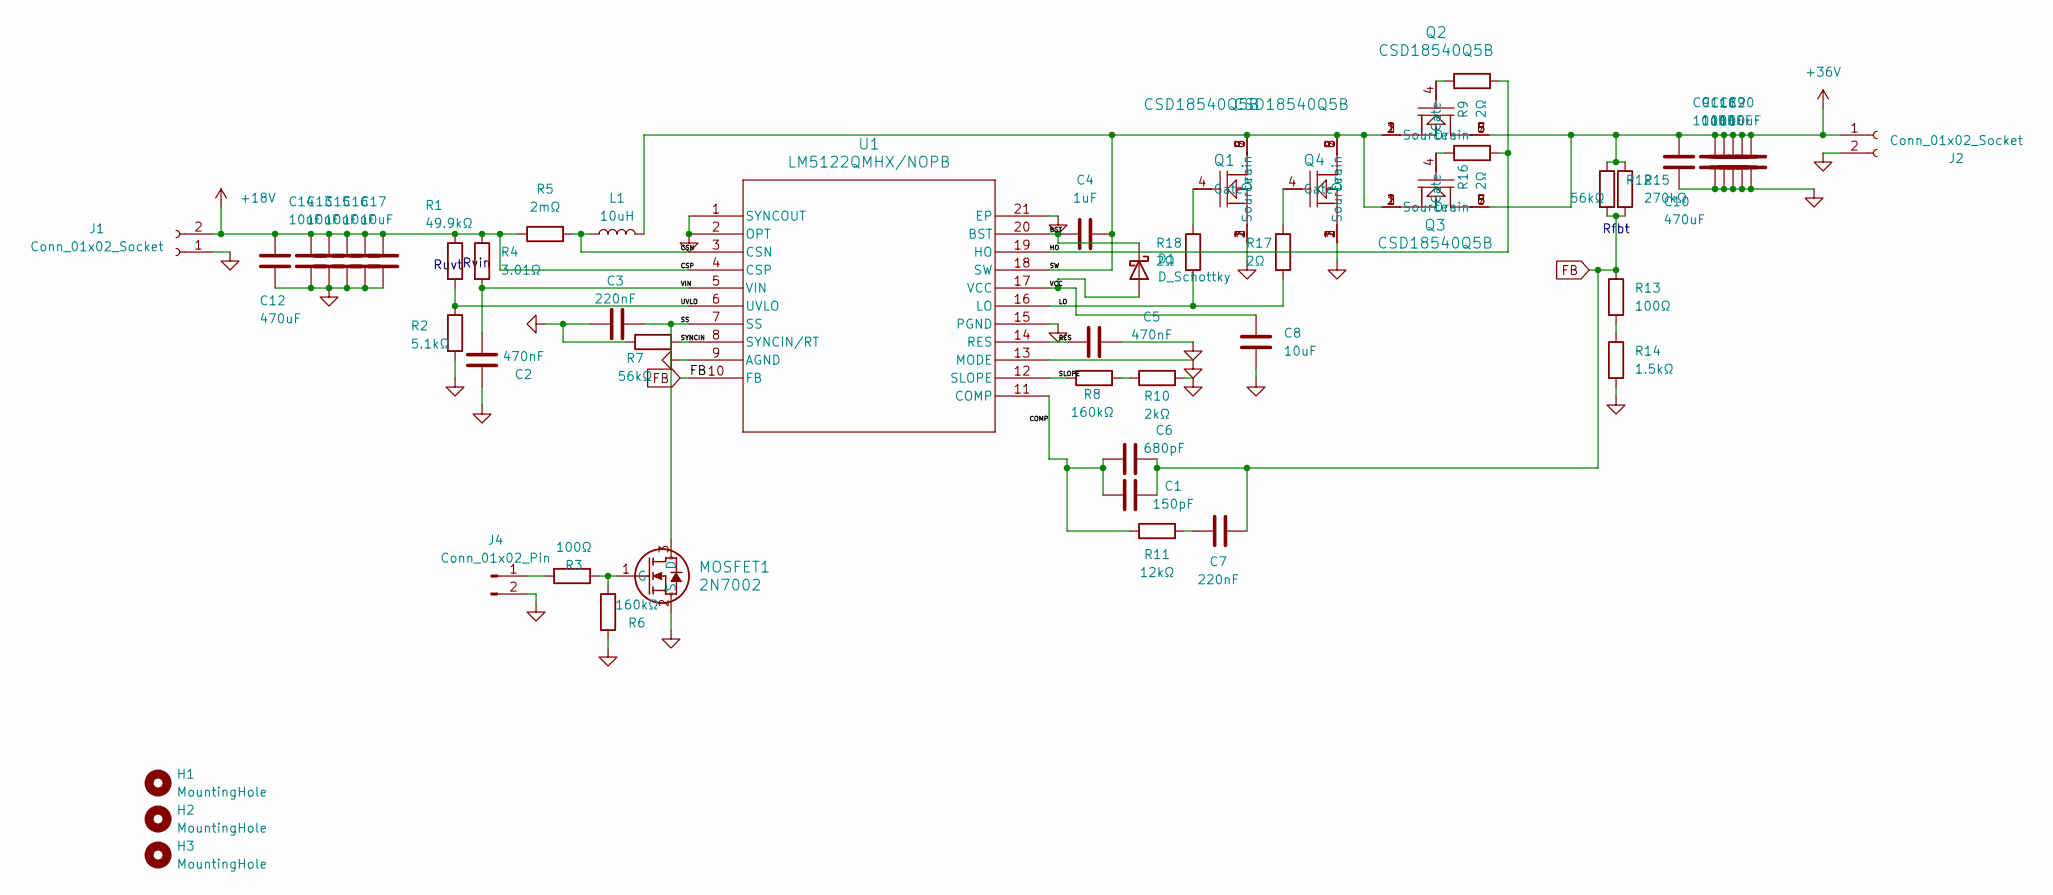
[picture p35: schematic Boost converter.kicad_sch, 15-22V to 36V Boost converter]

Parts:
C1: 150pF; C_0603_1608Metric; JLCPCB Part number C1594
C2: 470nF; C_0805_2012Metric; JLCPCB Part number C13967
C3: 220nF; C_0603_1608Metric; JLCPCB Part number C21120
C4: 1uF; C_0805_2012Metric; JLCPCB Part number C28323
C5: 470nF; C_0603_1608Metric; JLCPCB Part number C1623
C6: 680pF; C_0603_1608Metric; JLCPCB Part number C1630
C7: 220nF; C_0805_2012Metric; JLCPCB Part number C5378
C8, C9, C11, C13, C14, C15, C16, C17, C18, C19, C20: 10uF; C_0805_2012Metric; JLCPCB Part number C440198
C10, C12: 470uF; CP_Radial_D10.0mm_P5.00mm; JLCPCB Part number C5438877
D1: D_Schottky; D_SMA; JLCPCB Part number C18199198
H1, H2, H3: MountingHole; MountingHole_3.2mm_M3
J1, J2: Conn_01x02_Socket; TerminalBlock_MetzConnect_Type055_RT01502HDWU_1x02_P5.00mm_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
J4: Conn_01x02_Pin; PinHeader_1x02_P2.54mm_Vertical
L1: 10uH; IND_SER2918H_COC; JLCPCB Part number C3037600
MOSFET1: 2N7002; SOT-23TO-236_318-08_ONS; JLCPCB Part number C8545
Q1, Q2, Q3, Q4: CSD18540Q5B; DNK0008A; JLCPCB Part number C86513
R1: 49.9kΩ; R_0603_1608Metric; JLCPCB Part number C23184
R2: 5.1kΩ; R_0603_1608Metric; JLCPCB Part number C23186
R3, R13: 100Ω; R_0603_1608Metric; JLCPCB Part number C22775
R4: 3.01Ω; R_0603_1608Metric; JLCPCB Part number C49655781
R5: 2mΩ; R_2512_6332Metric; JLCPCB Part number C728306
R6, R8: 160kΩ; R_0603_1608Metric; JLCPCB Part number C22813
R7, R12: 56kΩ; R_0603_1608Metric; JLCPCB Part number C23206
R9, R16, R17, R18: 2Ω; R_0603_1608Metric; JLCPCB Part number C22977
R10: 2kΩ; R_0603_1608Metric; JLCPCB Part number C22975
R11: 12kΩ; R_0603_1608Metric; JLCPCB Part number C22790
R14: 1.5kΩ; R_0603_1608Metric; JLCPCB Part number C22843
R15: 270kΩ; R_0603_1608Metric; JLCPCB Part number C22965
U1: LM5122QMHX/NOPB; HTSSOP20; JLCPCB Part number C527477

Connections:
+18V: C12.1, C13.1, C14.1, C15.1, C16.1, C17.1, J1.2, R1.1, R4.1, R5.1, U1.4 (CSP)
+36V: C9.1, C10.1, C11.1, C18.1, C19.1, C20.1, J2.1, Q2.5 (Drain), Q2.6 (Drain), Q2.7 (Drain), Q2.8 (Drain), Q3.5 (Drain), Q3.6 (Drain), Q3.7 (Drain), Q3.8 (Drain), R12.1, R15.1
/BST: C4.1, D1.1 (K), U1.20 (BST)
/COMP: C1.1, C6.1, R11.1, U1.11 (COMP)
/CSN: L1.1, R5.2, U1.3 (CSN)
/HO: R9.2, R16.2, U1.19 (HO)
/LO: R17.2, R18.2, U1.16 (LO)
/RES: C5.1, U1.14 (RES)
/SLOPE: R8.1, U1.12 (SLOPE)
/SS: C3.2, MOSFET1.3 (D), U1.7 (SS)
/SW: C4.2, L1.2, Q1.5 (Drain), Q1.6 (Drain), Q1.7 (Drain), Q1.8 (Drain), Q2.1 (Source), Q2.2 (Source), Q2.3 (Source), Q3.1 (Source), Q3.2 (Source), Q3.3 (Source), Q4.5 (Drain), Q4.6 (Drain), Q4.7 (Drain), Q4.8 (Drain), U1.18 (SW)
/SYNCIN: R7.2, U1.8 (SYNCIN/RT)
/UVLO: R1.2, R2.1, U1.6 (UVLO)
/VCC: C8.1, D1.2 (A), U1.17 (VCC)
/VIN: C2.2, R4.2, U1.5 (VIN)
FB: C1.2, C6.2, C7.2, R12.2, R13.1, R15.2, U1.10 (FB)
GND: C2.1, C3.1, C5.2, C8.2, C9.2, C10.2, C11.2, C12.2, C13.2, C14.2, C15.2, C16.2, C17.2, C18.2, C19.2, C20.2, J1.1, J2.2, J4.2, MOSFET1.2 (S), Q1.1 (Source), Q1.2 (Source), Q1.3 (Source), Q4.1 (Source), Q4.2 (Source), Q4.3 (Source), R2.2, R6.1, R7.1, R10.2, R14.2, U1.1 (SYNCOUT), U1.2 (OPT), U1.9 (AGND), U1.13 (MODE), U1.15 (PGND), U1.21 (EP)
unnamed: C7.1, R11.2
unnamed: J4.1, R3.2
unnamed: MOSFET1.1 (G), R3.1, R6.2
unnamed: Q1.4 (Gate), R18.1
unnamed: Q2.4 (Gate), R9.1
unnamed: Q3.4 (Gate), R16.1
unnamed: Q4.4 (Gate), R17.1
unnamed: R8.2, R10.1
unnamed: R13.2, R14.1

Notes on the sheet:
Rvin
Ruvt
Rfbt

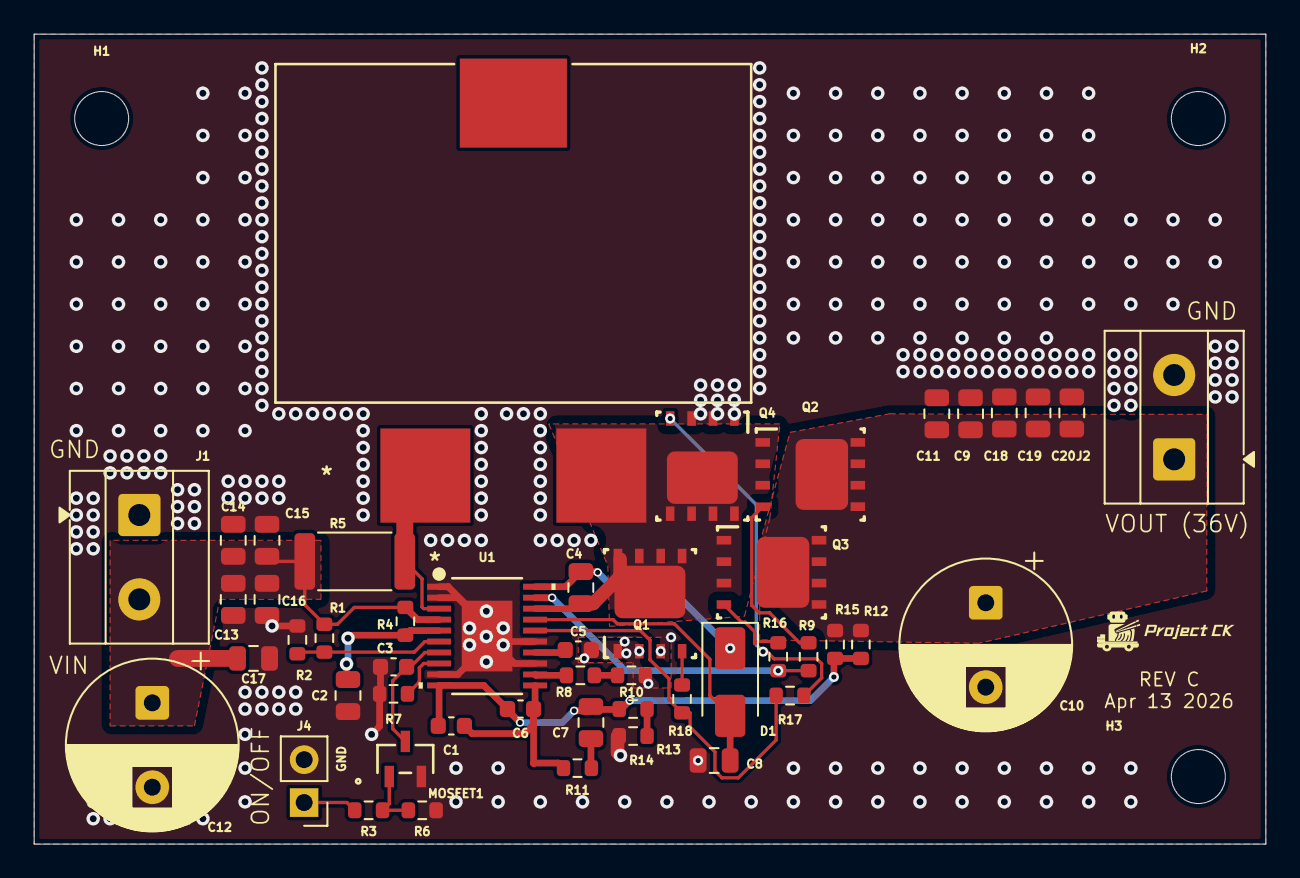
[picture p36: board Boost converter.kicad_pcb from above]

Board: 4 copper layers, 73.0 x 48.0 mm, 52 parts (0 on the bottom side), 26 nets.

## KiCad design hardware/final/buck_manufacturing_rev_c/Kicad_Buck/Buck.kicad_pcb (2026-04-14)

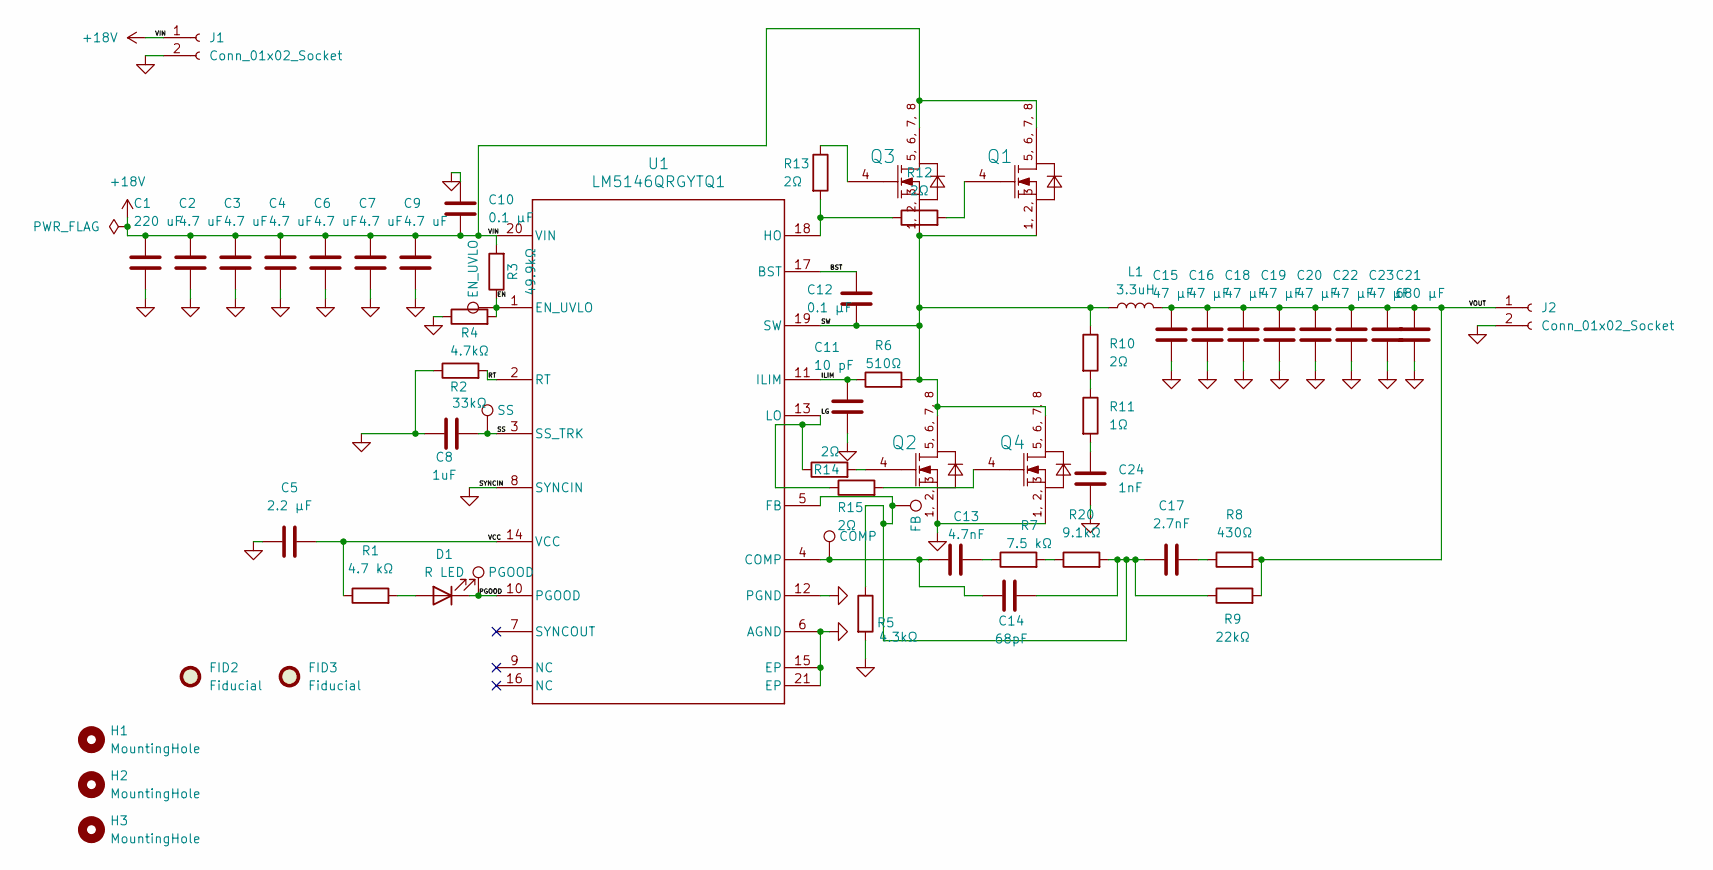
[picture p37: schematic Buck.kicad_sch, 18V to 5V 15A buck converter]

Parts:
C1: 220 uF; CP_Elec_4x5.4; JLCPCB Part Number C116389
C2, C3, C4, C6, C7, C9: 4.7 uF; C_1206_3216Metric; JLCPCB Part Number C29823
C5: 2.2 μF; C_0805_2012Metric; JLCPCB Part Number C377773
C8: 1uF; C_0603_1608Metric; JLCPCB Part Number C15849
C10, C12: 0.1 μF; C_0603_1608Metric; JLCPCB Part Number C14663
C11: 10 pF; C_0603_1608Metric; JLCPCB Part Number C1634
C13: 4.7nF; C_0603_1608Metric; JLCPCB Part Number C53987
C14: 68pF; C_0603_1608Metric; JLCPCB Part Number C28262
C15, C16, C18, C19, C20, C22, C23: 47 μF; C_1210_3225Metric; JLCPCB Part Number C96123
C17: 2.7nF; C_0603_1608Metric; JLCPCB Part Number C1609
C21: 680 µF; MA35V680M10X13; JLCPCB Part Number C48971043
C24: 1nF; C_0603_1608Metric; JLCPCB Part Number C1588
D1: R LED; LED_0603_1608Metric; JLCPCB Part Number C2286
FID2, FID3: Fiducial; Fiducial_1mm_Mask2mm
H1, H2, H3: MountingHole; MountingHole_3.2mm_M3
J1, J2: Conn_01x02_Socket; TerminalBlock_MaiXu_MX126-5.0-02P_1x02_P5.00mm; JLCPCB Part Number C8269
L1: 3.3uH; MS1770-3R3M; JLCPCB Part Number C18337521
Q1, Q2, Q3, Q4: BSC032N04LS; INF-PG-TDSON-8-FL; ManufacturerPartNumber BSC032N04LS; JLCPCB Part Number C194147
R1: 4.7 kΩ; R_0402_1005Metric; JLCPCB Part Number C25900
R2: 33kΩ; R_0603_1608Metric; JLCPCB Part Number C4216
R3: 49.9kΩ; R_0603_1608Metric; JLCPCB Part Number C23184
R4: 4.7kΩ; R_0603_1608Metric; JLCPCB Part Number C23162
R5: 4.3kΩ; R_0603_1608Metric; JLCPCB Part Number C23159
R6: 510Ω; R_0603_1608Metric; JLCPCB Part Number C23193
R7: 7.5 kΩ; R_0603_1608Metric; JLCPCB Part Number C23234
R8: 430Ω; R_0603_1608Metric; JLCPCB Part Number C23170
R9: 22kΩ; R_0603_1608Metric; JLCPCB Part Number C31850
R10, R12, R13, R14, R15: 2Ω; R_0603_1608Metric; JLCPCB Part Number C22977
R11: 1Ω; R_0603_1608Metric; JLCPCB Part Number C22936
R20: 9.1kΩ; C_0603_1608Metric; JLCPCB Part Number C23260
TP4: FB; TestPoint_Pad_1.0x1.0mm
TP5: COMP; TestPoint_Pad_1.0x1.0mm
TP6: PGOOD; TestPoint_Pad_1.0x1.0mm
TP8: SS; TestPoint_Pad_1.0x1.0mm
TP10: EN_UVLO; TestPoint_Pad_1.0x1.0mm
U1: LM5146QRGYTQ1; RGY0020B; JLCPCB Part Number C2876733

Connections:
+18V: C1.1, C2.1, C3.1, C4.1, C6.1, C7.1, C9.1, C10.2, J1.1, Q1.5 (DRAIN), Q1.6 (DRAIN), Q1.7 (DRAIN), Q1.8 (DRAIN), Q3.5 (DRAIN), Q3.6 (DRAIN), Q3.7 (DRAIN), Q3.8 (DRAIN), R3.2, U1.20 (VIN)
/BST: C12.1, U1.17 (BST)
/EN: R3.1, R4.2, TP10.1, U1.1 (EN_UVLO)
/ILIM: C11.1, R6.1, U1.11 (ILIM)
/LG: R14.1, R15.1, U1.13 (LO)
/PGOOD: D1.1 (K), TP6.1, U1.10 (PGOOD)
/RT: R2.2, U1.2 (RT)
/SS: C8.2, TP8.1, U1.3 (SS_TRK)
/SW: C12.2, L1.1, Q1.1 (SOURCE), Q1.2 (SOURCE), Q1.3 (SOURCE), Q2.5 (DRAIN), Q2.6 (DRAIN), Q2.7 (DRAIN), Q2.8 (DRAIN), Q3.1 (SOURCE), Q3.2 (SOURCE), Q3.3 (SOURCE), Q4.5 (DRAIN), Q4.6 (DRAIN), Q4.7 (DRAIN), Q4.8 (DRAIN), R6.2, R10.1, U1.19 (SW)
/VCC: C5.2, R1.1, U1.14 (VCC)
/VOUT: C15.1, C16.1, C18.1, C19.1, C20.1, C21.1, C22.1, C23.1, J2.1, L1.2, R8.2, R9.2
GND: C1.2, C2.2, C3.2, C4.2, C5.1, C6.2, C7.2, C8.1, C9.2, C10.1, C11.2, C15.2, C16.2, C18.2, C19.2, C20.2, C21.2, C22.2, C23.2, C24.2, J1.2, J2.2, Q2.1 (SOURCE), Q2.2 (SOURCE), Q2.3 (SOURCE), Q4.1 (SOURCE), Q4.2 (SOURCE), Q4.3 (SOURCE), R2.1, R4.1, R5.2, U1.6 (AGND), U1.8 (SYNCIN), U1.12 (PGND), U1.15 (EP), U1.21 (EP)
unnamed: C13.2, R7.1
unnamed: C17.2, R8.1
unnamed: C24.1, R11.2
unnamed: D1.2 (A), R1.2
unnamed: Q1.4 (GATE), R12.2
unnamed: Q2.4 (GATE), R14.2
unnamed: Q3.4 (GATE), R13.1
unnamed: Q4.4 (GATE), R15.2
unnamed: R10.2, R11.1
unnamed: R7.2, R20.1
unnamed: C13.1, C14.1, TP5.1, U1.4 (COMP)
unnamed: C14.2, C17.1, R5.1, R9.1, R20.2, TP4.1, U1.5 (FB)
unnamed: R12.1, R13.2, U1.18 (HO)

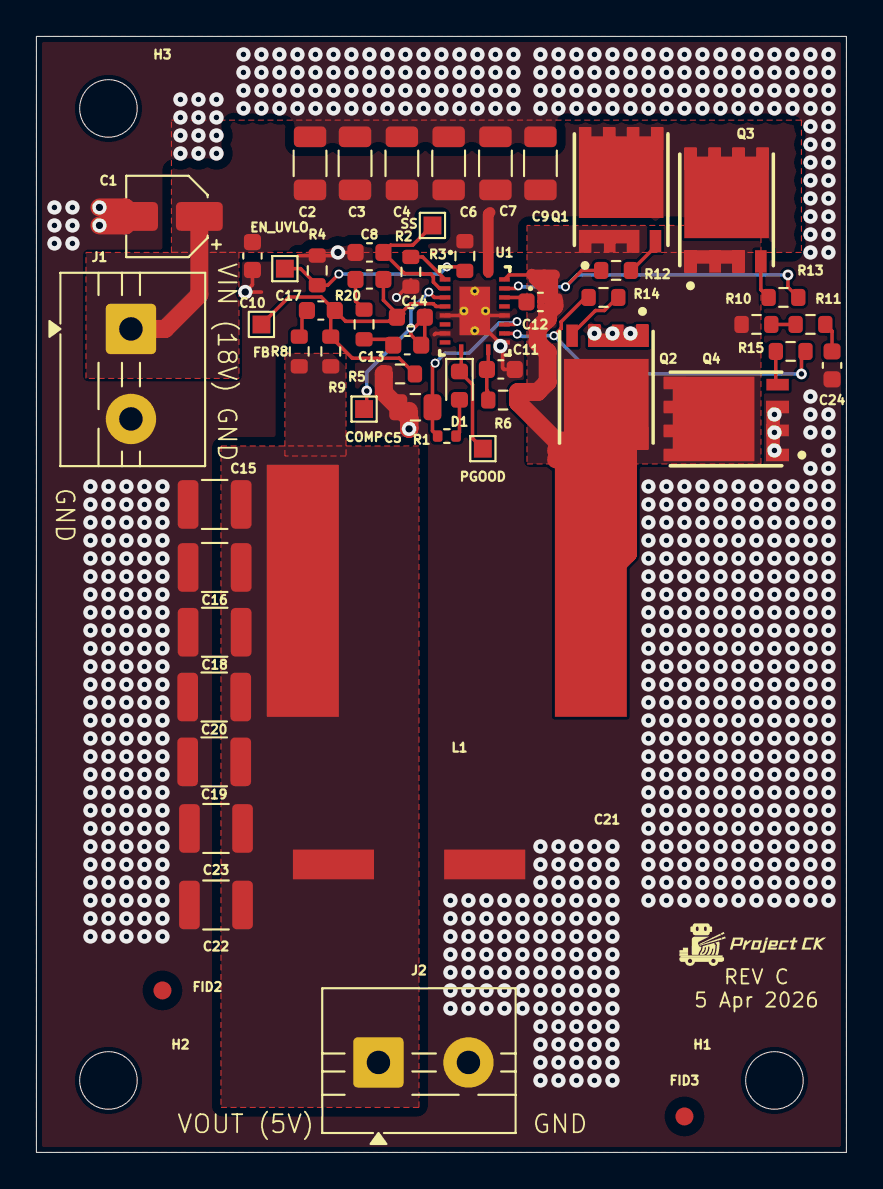
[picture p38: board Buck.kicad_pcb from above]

Board: 4 copper layers, 45.0 x 62.0 mm, 59 parts (0 on the bottom side), 25 nets.

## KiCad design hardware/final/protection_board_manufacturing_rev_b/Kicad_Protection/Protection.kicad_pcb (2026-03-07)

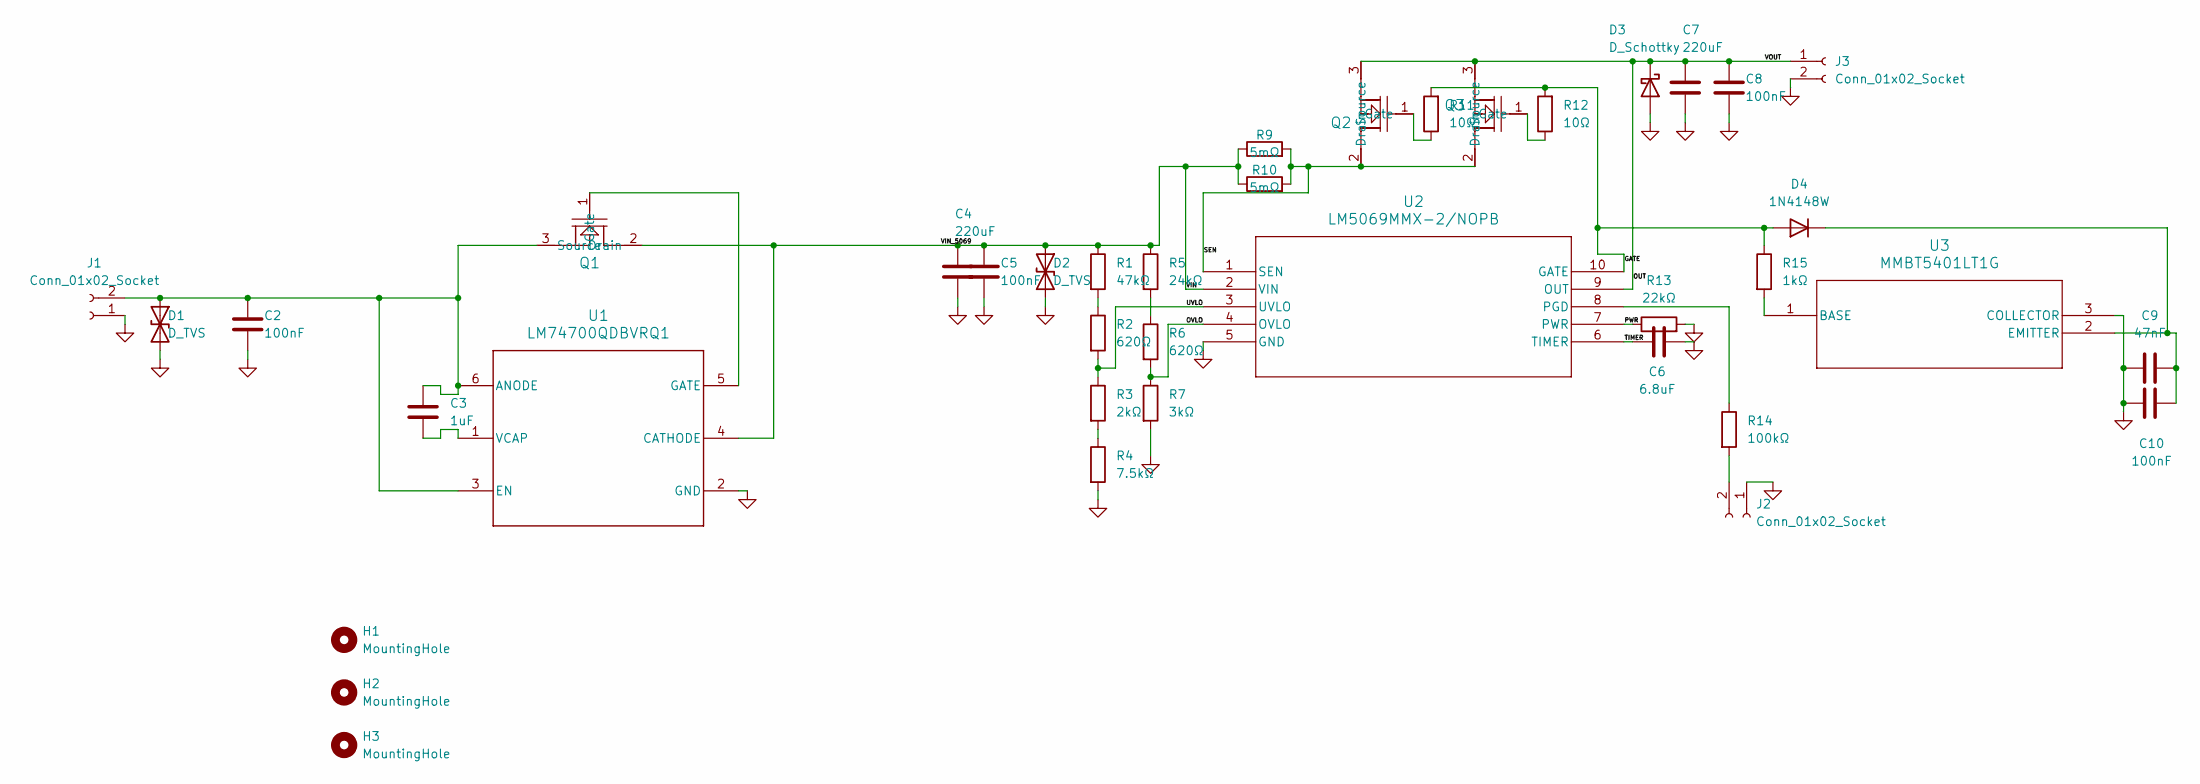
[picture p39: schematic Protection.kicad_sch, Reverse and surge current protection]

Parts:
C2, C5, C8, C10: 100nF; C_0603_1608Metric
C3: 1uF; C_0805_2012Metric
C4, C7: 220uF; CP_Radial_D10.0mm_P5.00mm
C6: 6.8uF; C_0603_1608Metric
C9: 47nF; C_0603_1608Metric
D1, D2: D_TVS; D_SMB
D3: D_Schottky; D_SMC
D4: 1N4148W; D_SOD-123
H1, H2, H3: MountingHole; MountingHole_3.2mm_M3
J1, J3: Conn_01x02_Socket; TerminalBlock_MaiXu_MX126-5.0-02P_1x02_P5.00mm
J2: Conn_01x02_Socket; PinHeader_1x02_P2.54mm_Vertical
Q1, Q2, Q3: CSD19536KTT; KTT0002A
R1: 47kΩ; R_0603_1608Metric
R2, R6: 620Ω; R_0603_1608Metric
R3: 2kΩ; R_0603_1608Metric
R4: 7.5kΩ; R_0603_1608Metric
R5: 24kΩ; R_0603_1608Metric
R7: 3kΩ; R_0603_1608Metric
R9, R10: 5mΩ; R_2512_6332Metric
R11, R12: 10Ω; R_0603_1608Metric
R13: 22kΩ; R_0603_1608Metric
R14: 100kΩ; R_0603_1608Metric
R15: 1kΩ; R_0603_1608Metric
U1: LM74700QDBVRQ1; DBV0006A_N
U2: LM5069MMX-2/NOPB; MUB10A
U3: MMBT5401LT1G; SOT-23-3_1P4X3P040_ONS

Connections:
/GATE: D4.2 (A), R11.2, R12.2, R15.1, U2.10 (GATE)
/OUT: C7.1, C8.1, D3.1 (K), J3.1, Q2.3 (Source), Q3.3 (Source), U2.9 (OUT)
/OVLO: R6.2, R7.1, U2.4 (OVLO)
/PWR: R13.1, U2.7 (PWR)
/SEN: Q2.2 (Drain), Q3.2 (Drain), R9.2, R10.2, U2.1 (SEN)
/TIMER: C6.1, U2.6 (TIMER)
/UVLO: R2.2, R3.1, U2.3 (UVLO)
/VIN: C4.1, C5.1, D2.1 (A1), Q1.2 (Drain), R1.1, R5.1, R9.1, R10.1, U1.4 (CATHODE), U2.2 (VIN)
GND: C2.2, C4.2, C5.2, C6.2, C7.2, C8.2, C9.1, C10.1, D1.2 (A2), D2.2 (A2), D3.2 (A), J1.1, J2.1, J3.2, R4.2, R7.2, R13.2, U1.2 (GND), U2.5 (GND), U3.3 (COLLECTOR)
unnamed: C2.1, C3.1, D1.1 (A1), J1.2, Q1.3 (Source), U1.3 (EN), U1.6 (ANODE)
unnamed: C9.2, C10.2, D4.1 (K), U3.2 (EMITTER)
unnamed: J2.2, R14.2
unnamed: Q1.1 (Gate), U1.5 (GATE)
unnamed: Q2.1 (Gate), R11.1
unnamed: Q3.1 (Gate), R12.1
unnamed: R1.2, R2.1
unnamed: R3.2, R4.1
unnamed: R5.2, R6.1
unnamed: C3.2, U1.1 (VCAP)
unnamed: R14.1, U2.8 (PGD)
unnamed: R15.2, U3.1 (BASE)

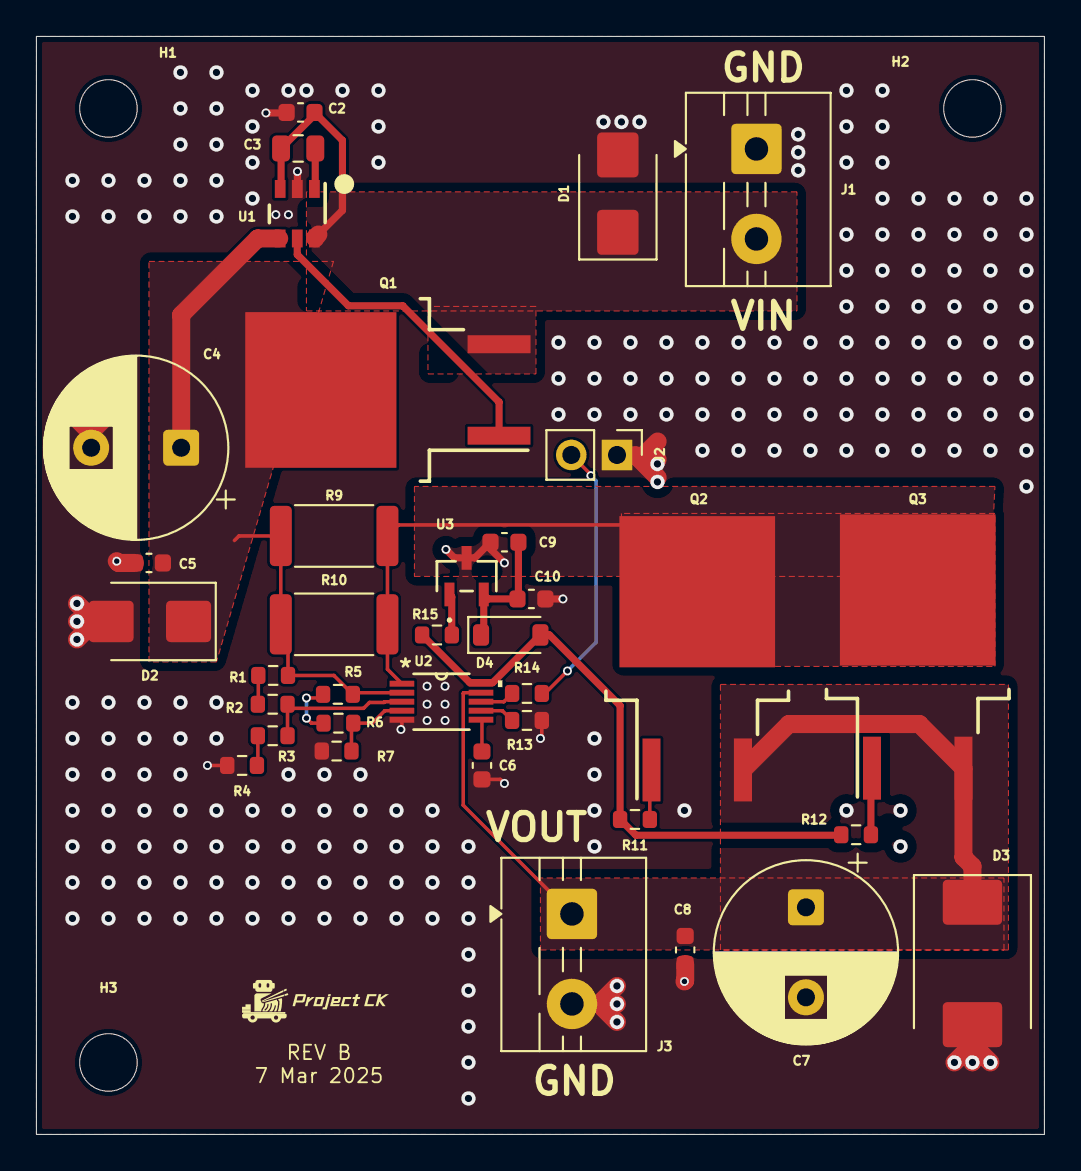
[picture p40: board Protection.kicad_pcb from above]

Board: 4 copper layers, 56.0 x 61.0 mm, 39 parts (0 on the bottom side), 21 nets.

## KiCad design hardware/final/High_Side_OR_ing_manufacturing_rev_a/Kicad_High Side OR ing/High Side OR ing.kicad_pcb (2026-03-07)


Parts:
C1, C2: 100nF; C_0805_2012Metric; JLCPCB manufactur number C28233
FID1, FID2, FID3: Fiducial; Fiducial_0.5mm_Mask1.5mm
H1, H2: MountingHole; MountingHole_3.2mm_M3
J1, J2, J3: Conn_01x02_Pin; TerminalBlock_MetzConnect_Type011_RT05502HBLC_1x02_P5.00mm_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
J4, J6: Conn_01x02_Pin; PinHeader_1x02_P2.54mm_Vertical
Q1, Q2: TPH2R608NH_L1Q kicad; SOP Advance_TOS; JLCPCB manufactur number C5379811
R1, R2: 100Ω; C_0603_1608Metric; JLCPCB manufactur number C22775
U1, U2: LM5050MKX-1/NOPB; MK06A; JLCPCB manufactur number C473393

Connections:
/GATE_1: Q1.4 (G), U2.5 (GATE)
/GATE_2: Q2.4 (G), U1.5 (GATE)
/VIN_1: J1.2, Q1.1 (S), Q1.2 (S), Q1.3 (S), U2.4 (IN)
/VIN_2: J2.2, Q2.1 (S), Q2.2 (S), Q2.3 (S), U1.4 (IN)
/VOUT: J3.2, Q1.5 (D), Q1.6 (D), Q1.7 (D), Q1.8 (D), Q2.5 (D), Q2.6 (D), Q2.7 (D), Q2.8 (D), R1.2, R2.2, U1.6 (OUT), U2.6 (OUT)
GND: C1.1, C2.1, J1.1, J2.1, J3.1, J4.2, J6.2, U1.2 (GND), U2.2 (GND)
unnamed: J4.1, U1.3 (OFF)
unnamed: J6.1, U2.3 (OFF)
unnamed: C1.2, R1.1, U1.1 (VS)
unnamed: C2.2, R2.1, U2.1 (VS)


Board: 4 copper layers, 36.0 x 31.0 mm, 18 parts (0 on the bottom side), 10 nets.

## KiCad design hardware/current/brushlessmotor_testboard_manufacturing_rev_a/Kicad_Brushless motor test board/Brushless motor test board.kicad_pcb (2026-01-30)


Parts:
A1: Arduino_Nano_Every; Arduino_Nano
J2, J3: Conn_01x02_Socket; TerminalBlock_MaiXu_MX126-5.0-02P_1x02_P5.00mm
J4: Conn_01x03_Pin; PinHeader_1x03_P2.54mm_Vertical

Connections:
+24V: J2.1, J3.2
/PWM: A1.8 (D5), J4.3
GND: A1.4 (GND), A1.29 (GND), J2.2, J3.1, J4.1


Board: 2 copper layers, 24.0 x 61.0 mm, 4 parts (0 on the bottom side), 3 nets.

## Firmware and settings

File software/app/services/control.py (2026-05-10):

import json

import pygame
import serial


class ControlService:
    def __init__(self, port="/dev/ttyACM0"):
        pygame.init()
        pygame.joystick.init()

        self.ser = serial.Serial(port, 115200, timeout=3)
        self.joystick = pygame.joystick.Joystick(0)
        self.joystick.init()

    def _serial_data(self):
        x = self.joystick.get_axis(0)
        y = self.joystick.get_axis(1)

        x = 0 if abs(x) < 0.05 else x
        y = 0 if abs(y) < 0.05 else y

        left = y - x
        right = y + x

        max_val = max(abs(left), abs(right), 1.0)
        left /= max_val
        right /= max_val

        left = int(left * 255)
        right = int(right * 255)

        return {
            "motors": {"left": left, "right": right},
            "servos": {
                "trap": self.joystick.get_button(1),
                "flag": self.joystick.get_button(0),
            },
        }

    def start(self):
        print(f"Control service started with serial {self.ser.port}")
        while True:
            pygame.event.pump()
            data = self._serial_data()
            self.ser.write((json.dumps(data) + "\n").encode("utf-8"))

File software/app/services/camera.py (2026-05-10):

import io
import os
import threading

import uvicorn
from fastapi import FastAPI
from fastapi.responses import FileResponse, StreamingResponse
from fastapi.staticfiles import StaticFiles
from picamera2 import Picamera2
from picamera2.encoders import JpegEncoder
from picamera2.outputs import FileOutput


class StreamingOutput(io.BufferedIOBase):
    def __init__(self):
        super().__init__()
        self.frame = None
        self.condition = threading.Condition()

    def write(self, buf):
        with self.condition:
            self.frame = buf
            self.condition.notify_all()
        return len(buf)


class CameraService:
    def __init__(self, size=(800, 600)):
        os.environ["LIBCAMERA_LOG_LEVELS"] = "*:ERROR"
        self.app = FastAPI()

        self.picam2 = Picamera2()
        self.config = self.picam2.create_video_configuration(main={"size": size})
        self.picam2.configure(self.config)

        self.output = StreamingOutput()
        self.encoder = JpegEncoder()

        self.picam2.start_recording(self.encoder, FileOutput(self.output))

        self.app.mount(
            "/static", StaticFiles(directory="static", html=True), name="static"
        )
        self._setup_routes()

    def _setup_routes(self):
        @self.app.get("/")
        def index():
            return FileResponse("static/index.html")

        @self.app.get("/stream")
        def stream():
            return StreamingResponse(
                self._frame_generator(),
                media_type="multipart/x-mixed-replace; boundary=frame",
            )

    def _frame_generator(self):
        while True:
            with self.output.condition:
                self.output.condition.wait()
                frame = self.output.frame
            if frame:
                yield (b"--frame\r\nContent-Type: image/jpeg\r\n\r\n" + frame + b"\r\n")

    def start(self, port=8000):
        print(f"Camera service started at http://raspberrypi.local:{port}")
        uvicorn.run(
            self.app,
            host="0.0.0.0",
            port=port,
            reload=False,
            workers=1,
        )

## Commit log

2025-02-02 Files for Raspberry Pi and Arduino added
2025-02-02 Rename Rasberry pi code.py to Raspberry pi code.py
2026-01-05 Initial import of Microver project files
    [Microver2025-B_Cu.gbr, Microver2025-B_Mask.gbr, Microver2025-B_Paste.gbr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]
2026-01-05 Reorganize top-level folders
    [Microver2025-B_Cu.gbr, Microver2025-B_Mask.gbr, Microver2025-B_Paste.gbr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]
2026-01-15 Add focused motor, encoder, and servo diagnostics
2026-01-30 Align naming, licensing, and cleanup
    - rename hardware/archive/assets folders to underscore style and move fab outputs accordingly\n- add explicit LICENSE, update README with repo map and license pointers\n- drop Finder .DS_Store files 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
    [BOM copy.csv, BOM.csv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]
2026-02-10 Add buck/boost rev B releases and refresh power docs
    - Document Standard Component Finder GPT utility.
    - Import boost converter Rev A/B KiCad projects, backups, bench PDFs/XLSX, and generated BOM/CPL/Gerbers; expand Rev B README with updated date, stack-up, value corrections, and EMI via shielding.
    - Add buck-only Rev B KiCad project/backups plus calculator, manufacturing files, README, and test procedure; retire motor-driver Rev B docs in favor of the buck-only spin.
    - Capture buck motor driver Rev A erratum, relocate motor_driver_test sketch into a dedicated folder, and add the KiCad snapshot/behavior log.
    - Refresh top-level README wording to point to the buck-only Rev B and update de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
    [BOM.csv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]
2026-02-12 hardware: refresh boost rev b outputs and add LM5050 OR-ing rev a package
    Update Boost Converter Rev B design/manufacturing files and add a new LM5050 OR-ing manufacturing package with standardized documentation.
    Boost Rev B:
    - Updated KiCad source files (.kicad_sch/.kicad_pcb/.kicad_prl), symbol libraries, footprint library entries, and fp cache.
    - Added MCU-controlled shutdown path by pulling LM5122 SS low via MOSFET.
    - Kept UVLO path for threshold function (not used for shutdown), so each re-enable triggers a fresh soft-start ramp from SS release.
    - Regenerated manufacturing artifacts: BOM, CPL, Gerbers, drill files, Gerber job, and Gerber.zip.
    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
    [BOM.csv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]
2026-02-12 hardware: add buck+motor driver rev a KiCad backup (2026-02-12_092032)
2026-02-22 repo: reorganize firmware layout and add current/archive hardware navigation
    This commit consolidates documentation + repository organization work so contributors
    land on active board revisions by default while preserving existing KiCad project
    paths and historical traceability.
    Hardware navigation and revision focus
    - Add a top-level hardware index at `hardware/README.md`.
    - Introduce `hardware/current/` as the canonical "start here" navigation layer
    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
2026-02-22 docs: simplify current status to latest board revisions
2026-02-22 refactor(hardware): move board revisions into current/archive
    Physically relocates board revision folders under hardware/current and hardware/archive, removes old pointer-only helper folders, and updates top-level hardware navigation docs and links to the new r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
    [BOM copy.csv, BOM.csv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]
2026-02-22 docs: simplify board READMEs by removing planned/action sections
2026-02-24 Reorganize KiCad hardware folders and add protection board project
    [BOM.csv, Boost converter.kicad_pcb, Boost converter.kicad_sch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]
2026-03-07 docs(hardware): add 2026-03-07 layout updates for current power boards
2026-03-07 hardware(pcb): update current Protection/Boost/Buck/ORing board files
    [Boost converter-B_Cu.gbr, Boost converter-B_Mask.gbr, Boost converter-B_Paste.gbr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]
2026-03-07 hardware(pcb): update buck motor driver kicad files
    [Buck.kicad_sch]
2026-04-05 Update hardware releases and simplify test procedures
    [BOM.csv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]
2026-04-14 Reorganize hardware folders and refresh docs
    [BOM.csv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]
2026-05-08 added flow charts, jingle, and mechanical folder
    [BOM.csv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]
2026-05-09 added components stl to mechanical folder
    [CK Project model (1).stl, Camera mount test.stl, Flag holder v2.stl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]
2026-05-10 added all step files for components and assemblies
    [BOM copy.csv, BOM.csv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]
2026-05-10 trying to add step files again
    [BOM copy.csv, BOM.csv, Ball bearing.step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]
2026-05-10 added a readme for the mechanical section
    [Cap prototype.step, Microver baseplate mock.step, Servo+MG996R.step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]
2026-05-10 Organize rover documentation and hardware assets
    [395443002.stp, DNH0008A.stp, Microver2026_Modular_Final.kicad_pcb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]
2026-07-09 Add buck board photo
2026-07-09 Add final control board photos
2026-07-14 Clarify final board assembly photos
2026-07-14 Add PCB STEP models to final hardware folders
    [Boost converter_3D.step, Buck_3D.step, High Side OR ing_3D.step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]

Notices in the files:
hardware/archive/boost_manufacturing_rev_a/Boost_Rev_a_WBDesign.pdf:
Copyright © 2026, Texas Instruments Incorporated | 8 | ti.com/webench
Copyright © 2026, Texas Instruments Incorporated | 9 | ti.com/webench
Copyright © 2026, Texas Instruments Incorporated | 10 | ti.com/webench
